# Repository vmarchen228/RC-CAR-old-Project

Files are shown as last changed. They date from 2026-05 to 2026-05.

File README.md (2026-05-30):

# RC Car Project

## Overview

This project involved designing and building a remote-controlled (RC) car as part of a college engineering project. The objective was to develop a functional vehicle capable of wireless control while integrating mechanical, electrical, and embedded systems concepts.

## Features

* Wireless remote control operation
* DC motor drive system
* Steering mechanism using servo motors
* Battery-powered system
* Custom chassis assembly
* Real-time control through a handheld transmitter

## Hardware Components

* Microcontroller (Arduino Uno/Nano)
* DC motors with motor driver module
* Servo motor for steering
* Wireless communication module (Bluetooth/RF)
* Rechargeable battery pack
* RC car chassis and wheels

## Software

The control software was developed in C/C++ using the Arduino IDE. The program handled:

* Motor speed control
* Steering angle adjustment
* Wireless command processing
* Safety and power management functions

## Results

The RC car successfully demonstrated wireless movement, steering control, and reliable operation during testing. The project provided practical experience in embedded systems, electronics integration, programming, and system debugging.

## Skills Developed

* Embedded Programming (C/C++)
* Arduino Development
* Electronics and Circuit Design
* Motor Control Systems
* Wireless Communication
* Mechanical Assembly
* Troubleshooting and Testing

## Future Improvements

* Autonomous navigation capabilities
* Obstacle detection using ultrasonic sensors
* Camera integration for FPV control
* Improved battery management system
* Mobile application control
RC CAR project

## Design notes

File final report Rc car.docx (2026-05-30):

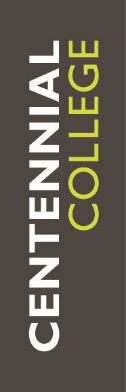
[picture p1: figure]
Image result for centennial college logo

School Of Engineering Technology and Applied Science (SETAS)

Advanced Manufacturing and Automation Technology (AMAT)

Automation and Robotics Technology

ROBO356- Design and Development Project 1

Section: 009 (Group 2)

Project Name: Remote Control Car

Title of Submission: Progress Report 1

Date: 17.10.2020

Professors: Alaeddin Bani Milhim

Florin Bratu

Submitted By:

Yaroslav Ishutko (301004764)

Vladislav Marchenko (301005635)

Declaration of Authorship (By Group 2)

We, Yaroslav Ishutko and Vladislav Marchenko, confirm that this breakdown of authorship represents our contribution to the work submitted for assessment and our contribution is our own work and is expressed in our own words. Any uses made within the Technology Report of the works of any other author, separate to the work group, in any form (ideas, equations, figures, texts, tables, programs), are properly acknowledged at the point of use. A list of the references used is included.

Abstract

Remote Control Car project is conducted by Group 2 on ROBO 356 section 009 to successfully design, build, troubleshoot and operate a remotely controlled vehicle capable of riding, steering, climbing low-pitched (up to 23°) ramp, gripping and transporting light objects (small coffee cup). As for week 5, all major aspects of vehicle design are finalized: it is 4-wheel, rear drive machine with a newly-developed “true” steering system controlled by servo motor. Major power components, such as battery, motors and a gripper are shifted to the back, while electronics and signal components (Ultrasonic sensor, Bluetooth module, Arduino UNO microcontroller platform) are located in front. It simplifies wiring, signal processing and allows to avoid extra high-to-low energy buffers (Arduino platform consumes 12V and is capable itself to share 5V for several field devices). Mechanical design description is supported by detailed in-scale 3D construction schematics of the vehicle and its particular components. Vehicle theoretical performance is analyzed, predicted and proved with all necessary formulas, it includes: Driving net force, Maximum vehicle speed, Steering Force, Gripping Force. Finished, ongoing and future construction activities are listed in chronological order and precisely described. As stated, major focus is held on assembling and testing steering mechanism – brand new and raw in design, but promising and unique feature. As a result of ongoing analytical and research process some minor changes were implemented in design besides steering. For example, it was decided to improve gripper design for higher safety and reliability. Finally, related and used references are accurately listed, as well, as descriptions to various formulas.

Table of Contents

- Cover Page 1
- Declaration of Authorship 2
- Abstract 3
- List of Illustrations 5
- Introduction 6
- Construction Activity
  1. Steering System 9
  2. Drive system construction 11
  3. Electrical/Power system construction 11
- Troubleshooting Activity 12
- Conclusion 15
- Bibliography (List of References) 16
- Glossary of terms 17
- Formula’s List 18

List of Illustrations

- Figure_1: Overall mechanical design of the vehicle 8
- Figure_2: Steering System Design 10
- Figure_3: Initial L-shape design 13
- Figure_4: Final L-shape design 13
- Figure_5: Gripper Schematic 14

Introduction

The goal of the project is to design a vehicle that will be capable of moving forward, backward, overcoming the inclined ramp , as well as to steer, grip the coffee cup and deliver it to the designated location. The car must be operated remotely and should be able to complete the task in 4 min. The cup must not touch the floor while being gripped.

The design has some limitations that should be considered while designing the vehicle.

List of limitations include such parameters:

1. Vehicle should be safe to competitors
2. Overall vehicle dimensions must not exceed 10 by 16 inches and be able to be carried by one person
3. Vehicle wheels must be in a range of 2 to 6 in in diameter
4. The only power supply that could be used is 12V Battery
5. To propel the vehicle only to specific 12V DC motors were given
6. No wood, toy components, glue , tape breadboard, are allowed
7. Vehicle must be self-contained

The design objective was to satisfy all the criteria mentioned above. To achieve the assigned configuration, the simplified physical- mathematical model was used to design the car for the scratch.

First of all it was decided that the vehicle will run on 4 wheels , 2 of which will be directly connected to the shafts of the 12 V DC motors. The other 2 wheel will be used in the steering mechanism. As a control will be used an app on the phone

Secondly, the design was based on the provided materials and parts. For example, the DC motors were meant to be attached to the base via L- bracket of specified shape. The base was supposed to be made of 10 by 16 inch aluminum plate and be able to old the battery an the rest of the components on it. Taking into consideration all the parameters it was decided to design from scratch the unique steering system with shafts, which will be connected to the wheels, and will be operated with help of servo motor to rotate left and right.

Thirdly, to satisfy the goal of the project additional components were obtained. These include: gripper operated by servo motor to grip the cup, Arduino UNO microcontroller as main logic element, Bluetooth module compatible with Arduino to connect to the phone app, Motor drive shield for Arduino to control 2 DC motors, Ultrasonic sensors to measure distance to objects, power switch and fuse for system safety and to avoid shortage in the wiring, LEDs and resistors for indication motion forward, backward or obstacle.

Design Section

Mechanical

The primary idea of mechanical design was to estimate the required base plate dimensions to fit the necessary components : L – brackets, DC motors, steering Mechanism, Battery, Arduino UNO, Bluetooth module, Motor shield, gripper and Ultrasonic sensor. By using the 3D Engineering software Inventor, all parts were drawn accurately to their real- life dimension and placed on the base plate. The estimated length was determined as 12 in. The length for Full steering system including Servo motor, and Steering mechanism was estimated in 5 inch length. By placing the 2 DC motors on the plate opposite to each other it was determined that the required width of the project will no exceed 7 inches.

The mechanical design had to satisfy 3 main features:

1. Motion Forward/Backward
2. Steering
3. Gripping the cup

For motion the Forward/Backward the 2 DC motors were used at the rear, in other words the vehicle was designed to have rear drive. DC motors were connected to the L brackets which itself were connected to the base plate at the rear . All connection were done by Hex cup bolts.

For Steering purpose the Steering Mechanism was designed because it has an advantage of more precise control.

While designing the steering mechanism few criteria were followed such as

1. The dimensions of the steering should not exceed 7 by 5 inch;
2. Shaft for the steering should be on the same level as shaft of the DC motor to avoid the base plate inclination.
3. Steering have to be attached to the base plate mechanically

By considering all of the above it was decided to design 2 Angle blocks of the L- Shape with shafts that will be connected to the base via bolts. From the beneath Angle blocks will be supported by the plate and from top by the base plate itself. To make sure that the Angle blocks steer to the same angle they were both attached to each other by the Steering Angle which will be connected to the servo later. By implying such construction the Angle blocks were lined up and were steering at the same angle when the Steering angle was rotated.

For Gripping the cup, the prototype of the Gripper was ordered and was modified.

The modification of gripper included facing off the unnecessary material from it claws and making the certain bolted connection to the servo motor and later to the plate itself.

After all main components were attached to the base plate, the central of mass was found and the rest of the components were placed to achieve equal weight load of rear drive and the steering mechanism. For such arrangement the heaviest component 12 V battery was placed between these two points.

All of the components were attached to the base plate by bolts except for the LEDs.

They were fitted in a specific bracket and then the bracket was tightly fitted to the base plate holes for the LEDs.

Two LEDs are present at the front and at the rear side for indication of Forward and Backward motion respectively.

The ultrasonic sensor was mounted at the front on holding bracket first and then attached to a 7 inch long holding panel that was attached to the base plate.

The Gripper which consists of Gripper and servo motor was decided to mount at the rear.

The battery was placed between Gripper and Arduino UNO, motor shield was placed at the top of the Arduino microcontroller as well as the Bluetooth module. Servo motor for the steering was placed between Arduino and ultrasonic sensor.

The secured mounting of battery and steering servo were achieved using holding plates tightened to the base plate by bolts foe each of them.

Switch and Fuse were placed closely to battery to avoid long wiring.

For more information regarding Mechanical Design please refer to the A

- Motor speed is 160 RPM (Zhengke Motor, 2020). The diameter of chosen wheels is 45 mm. These values will allow our car to achieve a maximum speed of 0,71m/s.

Vmax=RPMmax×L (2 ×π×R)

Lwheel = = 0.2673m

Vmax. = 160RPM*0.2673m (per rotation) = 42.77 m/minute ~ 0.71

- According to our calculations the approximate weight of the vehicle is around 2.5 kg. The torque produced by the motors is 39.24N*cm (Zhengke Motor, 2020) which will allow us to acquire a force of 34.8 N.

Freq. – force required to climb a ramp

Freq. = Ffr. + Fs. (Force of friction + Force of slip)

Freq=mgcos(a)×n+mgsin(a)

F req.= 2.5kg * 9.81m/s^2 * cos(23°) * 0.7 + 2.5kg * 9.81m/s^2 * sin(23°) = 25.39N

Fm - force provided by motors

Fm=2×T/R

Fm. = 2 * 39.24 N-cm /2.255cm = 34.80 N

This force is enough for the car to climb a ramp with an angle of 23 degree.

(Note* Actual Torque provided by DC motors, and, as a result, Motor Force is significantly higher than stated in manual)

- The steering servo motor will produce a Torque of 4 kg/cm (HITEC RCD USA, 2020). Considering the weight of the car is 2.5 kg and that most of the weight is concentrated on the Rear Drive. The weight we consider on steering wheels is 0,7kg. The mechanical coupling gives us approximately 4cm of lever.

F=T/L=4(kg)/(cm)/4 cm=1kg (Erjavec, 2002)

Therefore our car will have enough force to steer as F>W.

- To hold and transport a coffee cup securely F holding supposed to be greater than a cup weight.

Wcup (with ping-pong balls) ~ 25g * 9.81m/s^2 / 1000 ~ 0.25N

T=W×d , (distance from the motor shaft to the gripper contact point)

Thold = 0.25N * 7cm = 1.75 N-cm

Actual T of servo motor = 40.21 N-cm

sf=(Tac)/(Thold)

sf ~ 22 – Great safety factor ensures Cup is held securely even during acceleration and motion at maximum speed.

(Note* Presented calculations are also mentioned and justified in Milestone 2)

Construction Activity

The construction of the car consists of the three important parts.

1. The construction of the Steering System
2. The construction of the rear drive
3. Attachment of the components to the base plate
1. Steering System Construction

Our construction activities started with manufacturing parts for the steering mechanism and assembling the parts into one single Steering Assembly.

Our Steering Assembly primarily includes

1. 2 L-shape parts referred as Part A
2. 2 wheel shafts referred as Part A1
3. 2 Holding Plates referred as Part D
4. 1 Steering plate referred as Part B
5. 1 Motor-steering junction referred as Part C
6. 4 Socket Cap screws with washers and nuts

3 weeks are assigned for construction of the Steering mechanism. The activities are performed according to the schedule without delays.

As of date 10.11.2020 (Week4) we started construction of Steering Assembly

Part A manufacturing started and a rough L shape was obrained using Saw and Drill. (Week4, Vladislav Marchenko)

Future activities includes:

1. Milling the rough L-shape to acquire the precise dimensions needed (Week5, Vladislav Marchenko)
2. Drilling 3 holes in the Part A ( Week 5, Yaroslav Ishutko)
3. Manufacturing of Part A1 is required before obtaining the full shape of Part A ( Week 5, Yaroslav Ishutko)
4. The press fit of the shaft A1 into Part A (Week 5, Yaroslav Ishutko)
5. Manufacturing of parts D,C, B (Week5-6, , Yaroslav Ishutko)
6. Assembling of the Steering Mechanism ( Week6, Vladislav Marchenko)
2. Drive system construction

Second step of the construction involves attaching the rear drive to the base plate.

The whole construction activities consists of

1. Attaching the DC motors to the L brackets ( Week 7, Yaroslav Ishutko)
2. Drilling holes on the base plate to attach the L brackets and the Steering Assembly(Week 7, Vladislav Marchenko)
3. Attaching the L brackets, Steering Assembly to the plate, attaching wheels to the motor’s shafts and to the steering shafts. ( Week 7-8, Vladislav Marchenko)
3. Electrical/Power system construction

Third step is to attach the Arduino UNO, Bluetooth module, battery, ultrasonic sensor, gripper, motor drive shield, steering servo moto to the base plate.

Construction consists of:

1. Drilling holes on the base plate to attach the components with the fasteners. (Week 8, Yaroslav Ishutko)
2. Tighten the components to the plate with bolts and nuts ( Week8, Yaroslav Ishutko)

Troubleshooting Activities

Due to ongoing analysis of initial mechanical design and following troubleshooting in terms of optimization of car performance a number of changes were made. It included 1 major mechanical design change and 2 supplementary changes not reported in Milestone 2.

1. Development of “true” steering system

It was decided from the beginning to have rare drive car, meaning that both power wheels attached to 2 DC motor would be located on the back of the car, rather than in front. It satisfied our strategy to separate low-power (signal) and high-power (energy) systems. While Battery would be located closer to motors, powering them with 12V DC, major electrical components (Ultrasonic sensor, Bluetooth module ) would be located in front and powered with 5V by Arduino motherboard located in center-front part of the car. Thus, we solved 2 problems: firstly, we simplified wiring, secondly, we avoided using extra voltage step-down transition.

However, after comprehensive analysis it was decided to give up on steering by speed difference of power wheels. Rare drive and shifted back center of gravity made speed difference steering unreliable method. A completely new steering method had to be developed.

After gathering basic information about steering systems and car transmissions new unique steering system for Remote Control Car was developed. It came down to an idea of controlling wheels with servomotor. 2 L-shaped parts (Part A) are connected to wheels by pressing wheel shaft into one of its ends. L-shaped parts can rotate on shafts of a frame (Part D) connected to car bottom. Special steering plate moved by a servomotor control rotation of L-shaped parts and, accordingly, wheels.

(To find out more about its operation and structure refer “XXX”and Figure X)

New system provides increased controllability of rear drive and satisfies initial design limitations.

2. Minor change in a design of a steering system component

Initial design of L-shaped part of a newly-developed steering system included variety of different dimensions and sizes for different part components. It was done to ensure minimal weight and ideal balance in center shaft. After discussing initial design with faculty it was decided to develop more uniform and simplified part design contributing to reliability and simplicity of construction. Furthermore, initial idea of machining the wheel shaft within the solid part was rejected. Instead it was decided to drill a hole on the end of the part and press fit a separate wheel shaft into it (assembly). Aluminum was chosen as a construction material due to its low density (as for metals) and satisfactory rigidity.

Initial L-shape design vs revised design

Initial L-shape design, Figure_3

3. Minor Gripper Modification

Since new steering system required a lot of time and resources to be designed and constructed it was decided, in terms of time and resources management, to find most universal and reliable gripper solution. A standard Actobotic gripper, compatible with all standard servo motors, was chosen and order from one of suppliers. It also was assured that gripper is large enough to grab a small coffee cup – maximum width of gripper is 4.20” with total diameter of a cup no larger than 3-3.5”.

However, after analysis of Actobotic Gripper shape, it was determined to cut down and polish internal side of gripper so its shape would be ideally suitable for transportation of a specific coffee cup and its internal teeth (on the middle) are removed so cup would not be damaged in any case (safety). Rubber material of the gripper was defined as a tolerant for such deformations

Gripper Schematic, Figure_5

Internal Teeth

Note: original image was retrieved from: www.robotshop.com/ca/en/actobotics-perpendicular-standard-gripper-kit-b.html

c

Conclusion

- Vehicle performance expectations are clearly stated: moving forward, backwards, climbing inclined ramp, steering, gripping the coffee cup and delivering it to the designated location while controlled remotely via Bluetooth.
- Final mechanical design of the vehicle is fully described: 4 wheels, rare drive, “true” steering system controlled with servo motor, physical division of power and signal components.
- Multiple supporting 2D, 3D vehicle/components schematics are provided
- Vehicle performance expectations towards its Driving net force, Maximum vehicle speed, Steering Force, Gripping Force are described and proved by realistic calculations based on engineering formulas and data sheet information. Formulas also have an extra detailed description
- Construction activities for the past, present and future time periods are listed in chronological order and clearly described with division of responsibilities between group members.
- Major mechanical and supplementary Troubleshooting activities that have been conducted are listed, justified and described in-detail.
- All used References are mentioned and listed in alphabetical order

Bibliography

- Erjavec, J. (2002). Manual transmissions and transaxles (3rd ed.). Albany, N.Y: Delmar Thomson Learning.
- HITEC RCD USA. (2020). Hitec HS-422 Servo Motor Manual

Retrieved from: https://www.dfrobot.com/product-152.html

- Roboshop. Actobotics Perpendicular Standard Gripper Kit B

Retrieved from: https://www.robotshop.com/en/actobotics-perpendicular-standard-gripper-kit-b.html

- Zhengke Motor. (2020). ZGB37RG (A6587) Motor Manual

Retrieved from: https://www.zhengkemotor.com/product/zhengkemotor_product_Dc_Gear_Motor_37mm_ZGA37RG_ZGB37RG.html

Glossary of Terms

Bluetooth – technology of wireless data exchange between fixed and mobile devices.

Microcontroller – compact integrated electronic circuit capable of conducting complex logical and mathematical operations upon receiving input data. In other words – compact and simplified micro computer.

Motor Shield/Driver – a device or a module that is designed to easily and accurately control multiple motors and their parameters (speed, direction, torque and position). Can be controlled by microcontroller, PLC, PC.

Rear drive or Rear-wheel-drive – form of vehicle transmission at which only rare wheels are powered and driven by motor/s.

Shaft – round rotating machine element that transmits output power.

Formula’s list

Force exerted by servo motor for steering:

F=T/L

Force required for the car to climb the ramp:

Freq=mgcos(α)×μ+mgsin(α)

Force 2 DC motors can provide:

Fm=2×T/R

Maximum Speed of the vehicle:

Vmax=RPM×Lwh(2×π×R)

Torque required to be produced by servo motor to hold the cup:

T=W×d

Safety factor for the gripper:

sf=(Tac)/(Thold)

Group 2 – Progress Report 1 14

Running Head: Remote Control Car

Remote Control Car

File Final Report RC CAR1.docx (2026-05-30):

Image result for centennial college logo

School Of Engineering Technology and Applied Science (SETAS)

Advanced Manufacturing and Automation Technology (AMAT)

Automation and Robotics Technology

ROBO356- Design and Development Project 1

Section: 009 (Group 2)

Project Name: Remote Control Car

Title of Submission: Final Report

Date: 13.12.2020

Professors: Alaeddin Bani Milhim

Florin Bratu

Submitted By:

Yaroslav Ishutko (301004764)

Vladislav Marchenko (301005635)

Declaration of Authorship (By Group 2)

We, Yaroslav Ishutko and Vladislav Marchenko, confirm that this breakdown of authorship represents our contribution to the work submitted for assessment and our contribution is our own work and is expressed in our own words. Any uses made within the Technology Report of the works of any other author, separate to the work group, in any form (ideas, equations, figures, texts, tables, programs), are properly acknowledged at the point of use. A list of the references used is included.

Final Project Report Contribution Table
Section: | Person responsible:
Title Page | Yaroslav Ishutko
Declaration of Authorship | Yaroslav Ishutko
Abstract | Yaroslav Ishutko
Table of Contents | Yaroslav Ishutko
List of Illustrations | Yaroslav Ishutko, Vladislav Marchenko
Introduction | Vladislav Marchenko
Mechanical Design | Vladislav Marchenko
Electrical Design/Software | Yaroslav Ishutko
Troubleshooting activities | Yaroslav Ishutko
Data Analysis | Vladislav Marchenko
Conclusion | Vladislav Marchenko
Recommendations | Yaroslav Ishutko
Bibliography | Yaroslav Ishutko, Vladislav Marchenko
List of Acronyms | Vladislav Marchenko
Glossary of Terms | Vladislav Marchenko
Appendices | Yaroslav Ishutko, Vladislav Marchenko

Abstract

Remote Control Car project was conducted by Group 2 on ROBO 356 section 009 to successfully design, build, troubleshoot and operate a remotely controlled vehicle. Project was initially planned on 13 weeks (later shorten to 11 weeks). Due to personal effectiveness of all members of Group 002 and excellent group schedule it was possible to reach all main goals (and present the result to faculty) be the week 11. Thus, RC Car was successfully designed and constructed regarding and referring to initial technical requirements and, as a result, not only fully satisfies it, but also possesses several unique features that significantly increase its efficiency and are the subject to be discussed further in Final Report. Final Report on RC Car reflects all the technical requirements of the project (RC car should be capable of riding, steering, climbing the ramp, transporting light objects, etc..), rationale for the methods used, methodology (design principles, components and actuators used and their justification), bibliography (scientific references that had influence and shaped an initial idea of the project), design and troubleshooting activities during 11 weeks of project research and construction, resulting data analysis ( comparing of calculated theoretical and actual test data regarding RC Car performance) and overall project conclusions. Besides, some recommendations on further design project_1 course development are included as well as all the references, acronyms, terms are presented and listed in corresponding sections after the main part of the report. Finally, all technical data, formula references, final RC Car software code as well as both mechanical and electrical design figures are presented in acronyms.

Table of Contents

- Cover Page 1
- Declaration of Authorship 2
- Abstract 3
- List of Illustrations 5
  1. List of Figures 5
  2. List of Tables 5
- Introduction 6
- RC Car Design 7
  1. Mechanical Design 7
  2. Electrical Design/Software 9
  3. Troubleshooting Activities 11
    - Gripper installation 11
    - DC Motors selection and adjustment 12
    - Front wheels installation 13
- Data Analysis 14
- Conclusion 15
- Recommendations 16
- Bibliography 17
- List of Acronyms 18
- Glossary of Terms 19
- Appendices 20
  4. Appendices A 20
  5. Appendices B 24
  6. Appendices C 25
  7. Appendices D 27
  8. Appendices E 29
  9. Appendices F 31

List of Illustrations

List of Figures

1. Standard Hitec Servo Motor dimensions 11
2. Stainless Steel Pan Head Phillips Screw 12
3. Wheel Axial Locating using Spring Pins (schematics) 13

List of Tables

1. Project Contribution Table 2
2. I/O table 9
3. Data Table 14

Introduction

The goal of the project is to design a vehicle that will be capable of moving forward, backward, overcoming the inclined ramp , as well as to steer, grip the coffee cup and deliver it to the designated location. The car must be operated remotely and should be able to complete the task in 4 min. The cup must not touch the floor while being gripped.

The design has some limitations that should be considered while designing the vehicle.

List of limitations include such parameters:

1. Vehicle should be safe to competitors
2. Overall vehicle dimensions must not exceed 10 by 16 inches and be able to be carried by one person
3. Vehicle wheels must be in a range of 2 to 6 in in diameter
4. The only power supply that could be used is 12V Battery
5. To propel the vehicle only to specific 12V DC motors were given
6. No wood, toy components, glue , tape breadboard, are allowed
7. Vehicle must be self-contained

The design objective was to satisfy all the criteria mentioned above. To achieve the assigned configuration, the simplified physical- mathematical model was used to design the car for the scratch.

First of all it was decided that the vehicle will run on 4 wheels , 2 of which will be directly connected to the shafts of the 12 V DC motors. The other 2 wheel will be used in the steering mechanism. As a control will be used an app on the phone

Secondly, the design was based on the provided materials and parts. For example, the DC motors were meant to be attached to the base via L- bracket of specified shape. The base was supposed to be made of 10 by 16 inch aluminum plate and be able to old the battery an the rest of the components on it. Taking into consideration all the parameters it was decided to design from scratch the unique steering system with shafts, which will be connected to the wheels, and will be operated with help of servo motor to rotate left and right.

Thirdly, to satisfy the goal of the project additional components were obtained. These include: gripper operated by servo motor to grip the cup, Arduino UNO microcontroller as main logic element, Bluetooth module compatible with Arduino to connect to the phone app, Motor drive shield for Arduino to control 2 DC motors, Ultrasonic sensors to measure distance to objects, power switch and fuse for system safety and to avoid shortage in the wiring, LEDs and resistors for indication motion forward, backward or obstacle.

RC Car Design

Mechanical Design

The primary idea of mechanical design was to estimate the required base plate dimensions to fit the necessary components : L – brackets, DC motors, steering Mechanism, Battery, Arduino UNO, Bluetooth module, Motor shield, gripper and Ultrasonic sensor. By using the 3D Engineering software Inventor, all parts were drawn accurately to their real- life dimension and placed on the base plate. The estimated length was determined as 12 in. The length for Full steering system including Servo motor, and Steering mechanism was estimated in 5 inch length. By placing the 2 DC motors on the plate opposite to each other it was determined that the required width of the project will no exceed 7 inches.

The mechanical design had to satisfy 3 main features:

1. Motion Forward/Backward
2. Steering
3. Gripping the cup

For motion the Forward/Backward the 2 DC motors were used at the rear, in other words the vehicle was designed to have rear drive. DC motors were connected to the L brackets which itself were connected to the base plate at the rear . All connection were done by Hex cup bolts.

For Steering purpose the Steering Mechanism was designed because it has an advantage of more precise control.

While designing the steering mechanism few criteria were followed such as

1. The dimensions of the steering should not exceed 7 by 5 inch;
2. Shaft for the steering should be on the same level as shaft of the DC motor to avoid the base plate inclination.
3. Steering have to be attached to the base plate mechanically

By considering all of the above it was decided to design 2 Angle blocks of the L- Shape with shafts that will be connected to the base via bolts. From the beneath Angle blocks will be supported by the plate and from top by the base plate itself. To make sure that the Angle blocks steer to the same angle they were both attached to each other by the Steering Angle which will be connected to the servo later. By implying such construction the Angle blocks were lined up and were steering at the same angle when the Steering angle was rotated.

For Gripping the cup, the prototype of the Gripper was ordered and was modified.

The modification of gripper included facing off the unnecessary material from it claws and making the certain bolted connection to the servo motor and later to the plate itself.

After all main components were attached to the base plate, the central of mass was found and the rest of the components were placed to achieve equal weight load of rear drive and the steering mechanism. For such arrangement the heaviest component 12 V battery was placed between these two points.

All of the components were attached to the base plate by bolts except for the LEDs.

They were fitted in a specific bracket and then the bracket was tightly fitted to the base plate holes for the LEDs.

Two LEDs are present at the front and at the rear side for indication of Forward and Backward motion respectively.

The ultrasonic sensor was mounted at the front on holding bracket first and then attached to a 7 inch long holding panel that was attached to the base plate.

The Gripper which consists of Gripper and servo motor was decided to mount at the rear.

The battery was placed between Gripper and Arduino UNO, motor shield was placed at the top of the Arduino microcontroller as well as the Bluetooth module. Servo motor for the steering was placed between Arduino and ultrasonic sensor.

The secured mounting of battery and steering servo were achieved using holding plates tightened to the base plate by bolts foe each of them.

Switch and Fuse were placed closely to battery to avoid long wiring.

For more information regarding Mechanical Design please refer to the A

Electrical Design/Software

To begin with, it is necessary to point out that Electrical Design as well as Software are usually much more flexible in terms of troubleshooting. This is due the fact that all electrical or electronic components and programming space are heavily standardized and are available in already built-in universal packages/platforms for a moderate price. At our particular project of constructing Remotely Controlled Car we have also decided to use already developed and manufactured well-known universal electronic devices and available (easily accessible) user-friendly software to control mechanical actuators and signaling devices.

The key component or, in other words, the “brain” of our system became an Arduino Microcontroller integrated in universal Arduino Microcontroller Platform – Arduino Uno. This device is very flexible, customizable and has decent computing power that fully satisfies system requirements and an amount of data to be operated during normal performance. When choosing Arduino Uno platform it was ensured that there is enough Input/Output points for the number of operating device to be interfaced with Arduino. The list of used electronic devices is: Servo Motor1 (steering function), Servo Motor2 (gripping function), Ultrasonic Sensor (sensing distance and avoiding collisions), Bluetooth Module (serial communication between operator and RC Car), 2 x DC motors (prime movers) and 3 x signal LED’s (Forward, Reverse motion and Amber collision light). During the process of designing the electrical signal schematics for the system, 14 digital I/O pins of Arduino UNO were assigned to different devices as follows:

Input/Output Table

Arduino Platform-to-Pololu Motor Shield (interconnected pins)
Motor Direction Input A | Pin D2
Motor Direction Input B | Pin D4
Motor Enable Input | Pin D6 (Pwm)
Motor Speed Input | Pin D9 (Pwm)

Pololu Motor Shield-to-field devices (wire connections)
Forward LED Output | Pin D10
Reverse LED Output | Pin D11
Amber LED Output | Pin D12
Servo 1 Signal/Pulse Output | Pin D3
Servo 2 Signal/Pulse Output | Pin D5
Ultrasonic Sensor Trigger Output | Pin D7
Ultrasonic Sensor Echo Input | Pin D8
TX to Bluetooth RX Output | TX/Pin D1
RX from Bluetooth TX Input | RX/Pin D0

Power Connections of Pololu Motor Shield
Battery (main power supply) 12V | VIN wire terminal
Battery (main power supply) GND | GND wire terminal
2x DC Motor “+” | M1A wire terminal
2x DC Motor “-“ | M1B wire terminal

Power Connections of Arduino Platform
Battery (main power supply) | Power port (by multi-purpose power cable)

Note that Arduino UNO Microcontroller Platform was fully interfaced (100% compatible) with Pololu Motor Shield (Motor Driver), meaning that each pin of Arduino was interconnected with corresponding pin of Pololu platform and, as a result, pins were shared. Pololu Motor Shield was used as a special high-power interface for low-power Arduino controller (low currents, 5V outputs) and high-power 12V outer system.

Researching the “Pololu Simple Motor Controller User’s Guide” by Pololu, it was found out that pins D2 and D4 would control motor’s direction (terminals A1 and A2), pin D6 acts as a motor’s movement enabler and, finally, pin D9 (PWM~ pin) is a motor speed Input. It is important to mention that 2 DC motors were wired together (parallel) to a single motor terminal. It saved 4 extra pins on Arduino/Motor Shield and ensured that both motors receive exactly same commands during operation, as needed.

Both, steering Servo and gripping Servo (Hitec servo motors were used) required 5V and GND (was taken from 5V output on Pololu Motor Driver) and a controlling signal from one of 14 digital pins. It was important for correct operation that the pins for both servo motors are “PVM” Output pins (~ sign). It was needed for proper control by applying a series of high-frequency pulse signals. Thus, pins D3 and D5 were chosen.

According to the “The HC-05 Bluetooth Module with Arduino” article, Bluetooth module needed only 3.3 V power source that was also presented on Arduino Motherboard Platform. Practically, it was proved that 3.3V is enough for uninterrupted operation. Thus, Bluetooth module had a separate reliable power supply. Pins for serial communications (Rx and Tx) were set as D1 and D0 respectively. Servo Motors were easy to control using special Arduino code library represented in Appendices: C.

Ultrasonic Sensor (HC-SR04) required signal pins to be configured as digital Input and Output. Pins D8 and D7 were chosen respectively and, later, configured. Sensor uses Arduino Timer Module to measure the distance having the speed of ultrasonic waves as known value. It measures time between sending and receiving reflected signal and, using, timing and program calculations, user is able to determine exact position. Sensor was powered by stable 5V Output.

3 signal LED’s received pins at last order, as there were absolutely no special requirements for them. Pins D10, D11 and D12 were assigned to 2 Forward, 2 Reverse and 1 Amber light. 330 resistor was wired between Output pin and each LED to ensure proper voltage drop (1.8V) on LED (5V Output pins) for their correct operation. All leads were isolated, so no shortage could occur.

For common sense safety purposes, 2 A fuse and Main Power Switch were installed between Main Power Source (12V Battery) and the rest of the system.

To learn more about electrical system design for RC Car – refer to Appendices B.

Troubleshooting activities

Gripper installation

Considering the fact that RC Car had to climb a steep ramp (~23*) it was decided that the gripper has to be mounted at a certain elevation as for the level of the car base plate. After standard Actobotics Gripper (Kit B) was found and chosen for our project due to its compatibility with a series of standard servo motors, its was decided to secure gripper on the top of the servo motor, while using bolts, secure them both to the base plate. This method satisfied our initial requirements, was easy to implement and was anticipated by servo motor and gripper mechanical structure. The only problem seemed in the availability of thin (to fit special mounting holes on gripper’s sides), but very long (gripper height together with servo motor height resulted in around 1.65” length) and rigid bolts. As Centennial College Inventory couldn’t satisfy our need, we (Group #002) conducted our independent research and found bolts of satisfactory size (6-32 Thread, 2-1/2" Long bolt). Set of 2 bolts, 2 nuts and 2 washers was acquired and used for successful and safe installation of gripper.

Figure 1, Standard Hitec Servo Motor dimensions

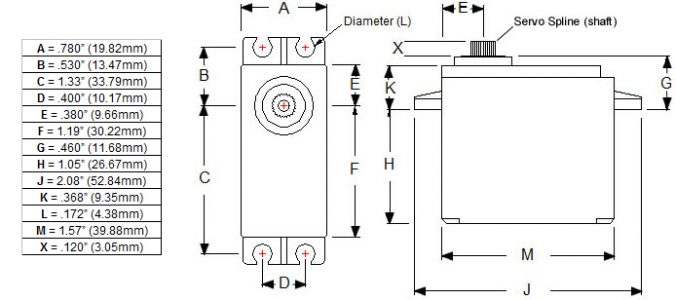
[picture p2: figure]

Note* Original image is reprinted from DFRobot , Hitec HS422 Servo.

Retrieved from: https://www.dfrobot.com/product-152.html

Figure 2, Stainless Steel Pan Head Phillips Screw

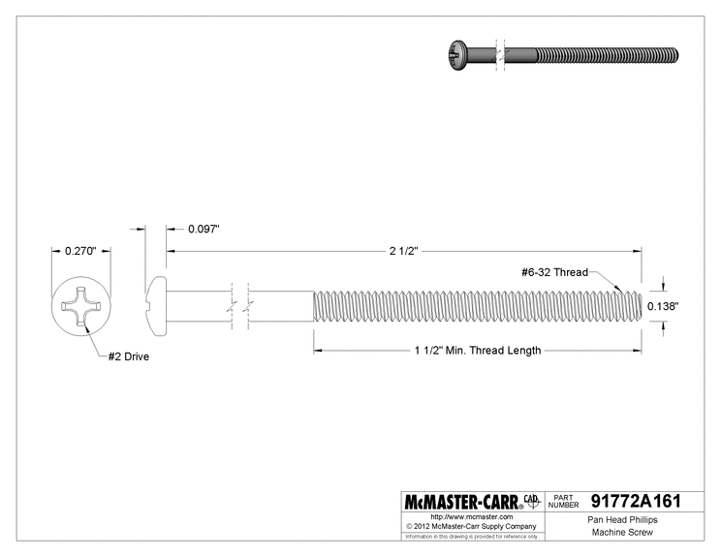
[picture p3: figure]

Note* Original image is reprinted from McMASTER-CARR, (2020), Passivated 18-8 Stainless Steel Pan Head Phillips Screw.

Retrieved from: https://www.mcmaster.com/91772A161/

DC Motors selection and adjustment

As per initial idea and construction design, steering was meant to be achieved by using separate front wheel transmission controlled by a servo motor. In this case, both 2 DC motors (prime movers) were connected to same output terminals, received same signals at the same time and had to rotate with exact same speed to achieve straight linear movement and precise control. 2 DC motors, acquired from Centennial College initially were proved to be asynchronous in terms of output speed, even though they both received voltage from the same source. To solve this problem, motors were exchanged on a pair with exact same characteristics (consumed current and voltage drop on motors was measured by multimeter: 108mA and 11.7V drop). Voltage drop, consumed current were repeatedly remeasured as motors were secured in L-shape brackets using multiple bolts. As a result – exact speed of both motors was achieved. Deviation of the car during normal performance was observed to be minimum (1-3* or 7-8 cm over 3 m distance).

Front wheels installation

Due to unique design of the car overall and of the steering structure in specific, there was a strict design requirement for both front wheels to spin or rotate freely on the shaft (press fitted into the rotating angle element of the steering system) while being reliably secured axially on the same shaft. To achieve this, it was decided to use tiny pins (pin – device commonly used to axially secure rotating elements on the shaft) from both sides of the each wheel – 4 pins in total. Holes were drilled on small and round shaft, so great precision was achieved using milling machine (up to 0.0001” precision). Wheels and corresponding pin holes for them were located on exact same distance from both sides to ensure precise steering. Holes’ diameter was only around 0.05”. Spring pin type was used – it expands while placed into the hole, thus preventing any slippage and unsecure fixation.

Figure 3, Wheel Axial Locating using Spring Pins (schematics)

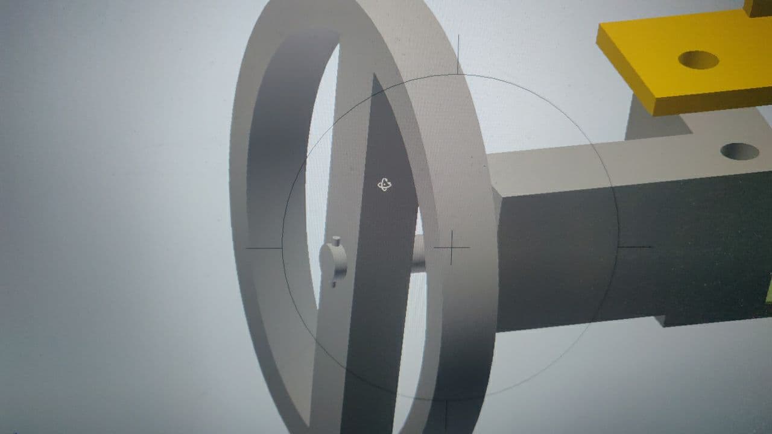
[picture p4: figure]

Note* Picture is taken from RC Car mechanical drawing/schematics - Appendices A

Data Analysis

Based on the acquired material and components it became possible to compute the maximum speed, torque, friction with surface and gripper holding force.

Motor Speed | 160 RPM
Wheels diameter | 45 mm
Wheels Circumference | 0,2673 m
Max Speed | 0,71m/s
Weight | 2,5 kg
Motors Toque (Total) | 39,24 N*cm
F required | 25,39 N
F acquired | 34,8 N
Steering motor Torque | 4 kg*cm
Steering Motor Force | 1 kg
Force to hold cup | 0,25 N
Torque achieved at the gripper | 40,21 N*cm
Safety factor for Gripper | 22

However in reality it was found out that the car achieve a slightly higher speed than was calculated , as well as the Actual torque produced by the motors appeared to be higher will allowed the car to climb even more inclined ramp than 23 degrees.

For the actual speed it was measured to achieve of 0,83 m/s while measuring time to reach 2,5 m for time of 3 s.

Construction of the steering mechanism was estimated to add additional 0,7 kg to total weight of the car and based on that number the servo motor required torque for steering was calculated .

The design was mostly symmetric, combined with synchronous rotating motors it allowed to achieve a straight motion on the test.

Due to firm connection to the base with the bolts, the vibration occurred during test was insignificant and therefore making the vehicle able to sustain self-contained for a long time.

The use of servo motor made it possible to achieve precise steering even during the maximum speed.

Conclusion

In conclusion, the designed vehicle managed to complete all the tasks and objectives that were set, furthermore the outcome of the project was more satisfactory than expected in terms of vehicle technical characteristics: the speed achieved was higher than anticipated , so was the ability of overcoming more inclined ramps and carrying more heavy objects. The straight motion became possible due to symmetric design and precise steering control. Overall, the method of applying physical-mathematical model, combined with designing the vehicle in the CAD engineering software was effective. The further design improvements are possible in achieving higher speed and acceleration by adding gear box to the rear drive and improving the steering system by adding additional motors to the front drive, thus making car full drive, or replacing motors with more powerful analogs.

Recommendations

Overall, Design and Development Project_1 course possesses satisfactory academic quality is intensive and has both theoretical and practical activities to be completed during the semester.

On the other hand, there certainly is a room for further development and improvements.

We introduced several possible improvements that, in our opinion, could contribute to the course in future:

- Theoretical background

From the practical experience of many students, 2 previous semesters of studying do not provide sufficient academic background and specific applicable knowledge that could help during comprehensive RC Car design and construction. We suggest to implement concepts of automation and automotive systems design, automotive motion and power transmissions and physics/calculations for power transmissions/drives as a part of some engineering courses prior to Design and Development Project_1. It also refers to the study of microcontrollers and C# programming – having both courses in same semester, students are not able to spend time effectively, as, most of the time, they do not possess enough knowledge to program car yet.

- Project Evaluation

We find it right to evaluate final outcome of student project. However, we suggest to evaluate design component rather than performance. First of all, the objective of the course is to learn, investigate and create. You should support unique decisions, “thinking out of the box” and creativity, rather than immediate effectiveness in particular situation. Especially, when every group has exact same power source and prime movers. In the end of the day it comes to: minor factors (that are even hard to account) and simple luck. Also, each project/design should be evaluated independently, as the last team in the strongest section may still be better than the best team in weakest section, yet, having totally different grades for the same performance.

- Inventory and Tools

Even though most of the machinery in College Machine Shop may be old, it still functions well. The only suggestion as for heavy equipment and machinery would be to acquire a number of equipment with higher precision for delicate/high-precision material processing. However, there is totally different situation with availability of various hand tools, minor details and raw material. It would be much better if student had access (while constructing a complex system) to a various materials (metal sheets, plastic, insulators, tubes) – not only occasional leftovers. Also, often used tools (end mills, chucks for milling, calipers, etc) are usually in poor condition and have to be replaced. Overall expansion of inventory volume and diversity would definitely contribute to the course quality and student performance.

Bibliography

DFRobot , Hitec HS422 Servo.

Retrieved from: https://www.dfrobot.com/product-152.html

Makersspaces.com, Arduino For Beginners.

Retrieved from: https://www.makerspaces.com/arduino-uno-tutorial-beginners/

McMASTER-CARR, (2020), Passivated 18-8 Stainless Steel Pan Head Phillips Screw.

Retrieved from: https://www.mcmaster.com/91772A161/

Pololu, (2020), Pololu Simple Motor Controller User’s Guide.

Retrieved from: https://www.pololu.com/docs/0J44

Sanjay Rajure (2019, May18), The HC-05 Bluetooth Module with Arduino.

Retrieved from: https://www.comprolive.com/2019/05/the-hc-05-bluetooth-transmitterreceiver.html

List of Acronyms

CAD – Computer Aided Drafting

RC – Remotely Controlled

DC – Direct Current

LED – Light Emitting Diode

GND – Ground

I/O – Input/ Output

Glossary of Terms

Bluetooth – technology of wireless data exchange between fixed and mobile devices.

Microcontroller – compact integrated electronic circuit capable of conducting complex logical and mathematical operations upon receiving input data. In other words – compact and simplified micro computer.

Motor Shield/Driver – a device or a module that is designed to easily and accurately control multiple motors and their parameters (speed, direction, torque and position). Can be controlled by microcontroller, PLC, PC.

Rear drive or Rear-wheel-drive – form of vehicle transmission at which only rare wheels are powered and driven by motor/s.

Shaft – round rotating machine element that transmits output power.

Appendices

A: (Mechanical Drawings)

B: (Electrical drawings/schematics)

Note* Electrical schematics left unchanged from Milestone 4

C: (Arduino Microcontroller program code)

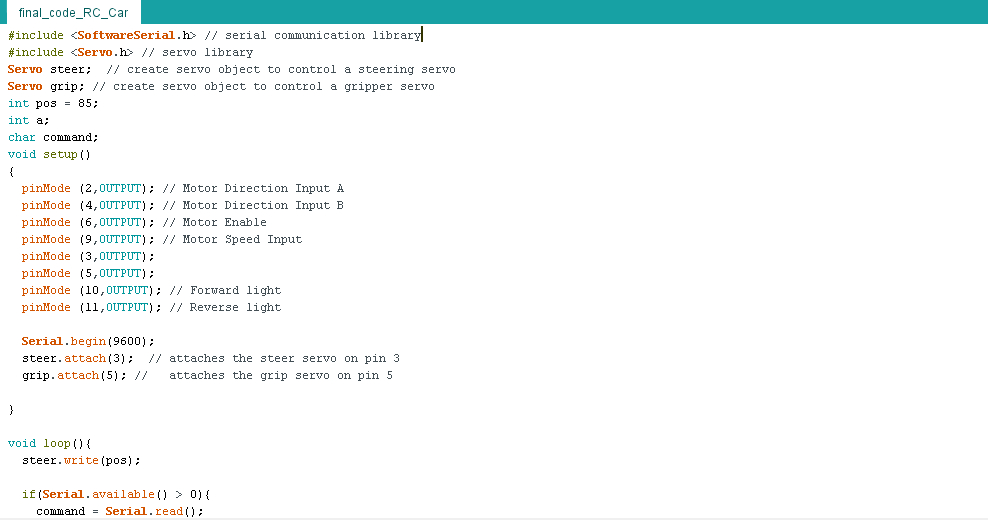
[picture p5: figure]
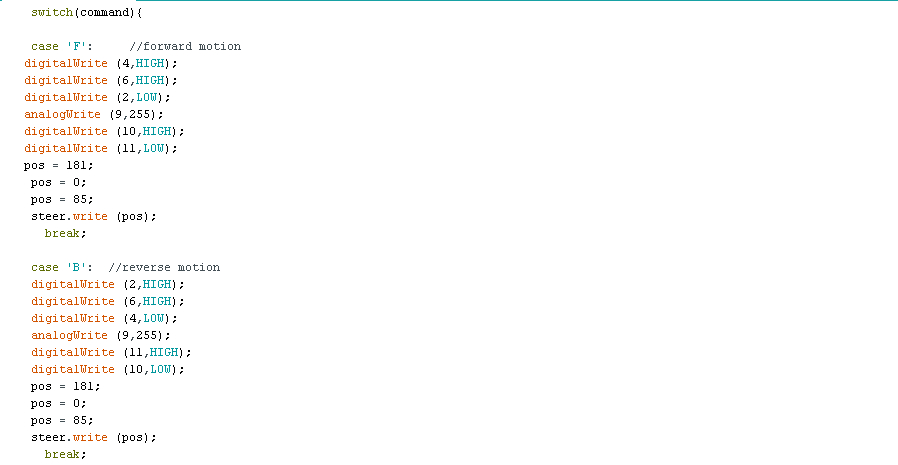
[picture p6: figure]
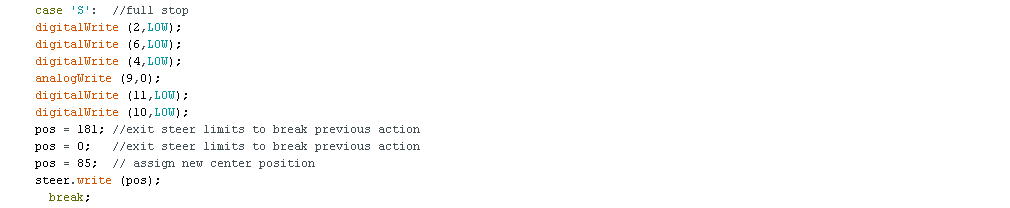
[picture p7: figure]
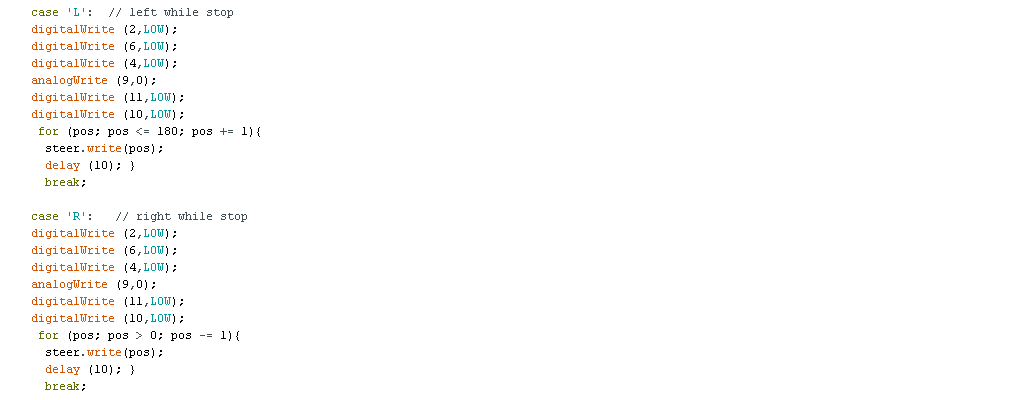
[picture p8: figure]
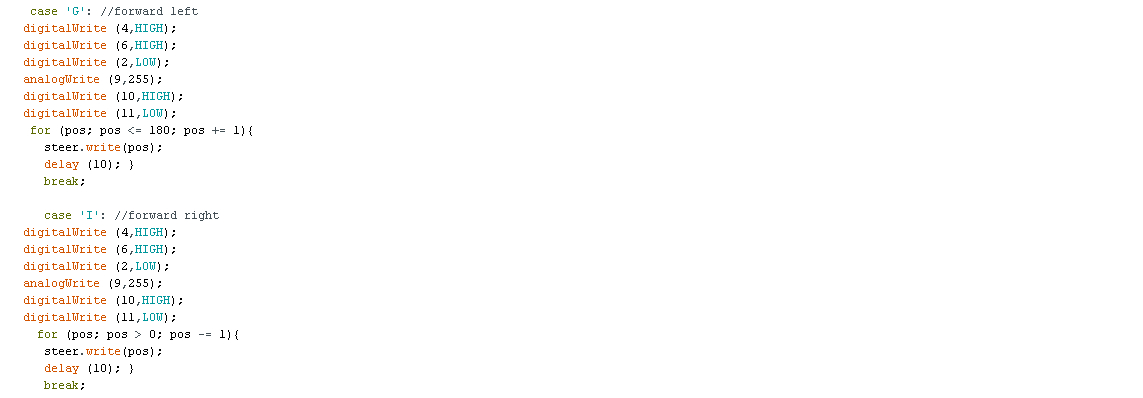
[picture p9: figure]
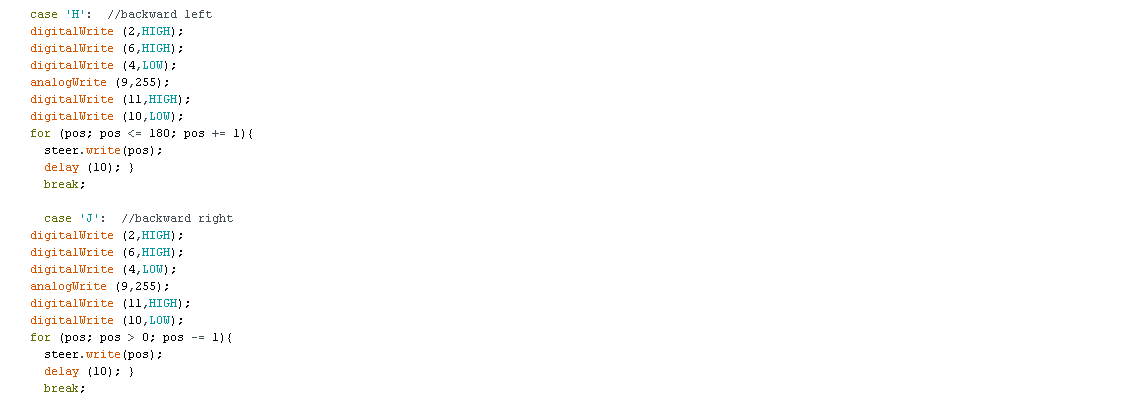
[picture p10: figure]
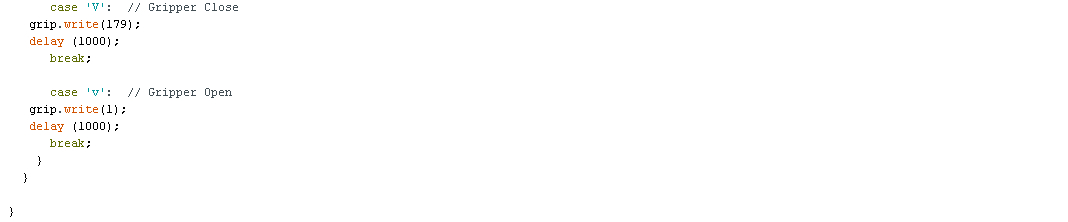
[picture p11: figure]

D: (Project Design Calculations – Formulas’ list and full calculation)

Force exerted by servo motor for steering:

F=T/L

Force required for the car to climb the ramp:

Freq=mgcos(α)×μ+mgsin(α)

Force 2 DC motors can provide:

Fm=2×T/R

Maximum Speed of the vehicle:

Vmax=RPM×Lwh(2×π×R)

Torque required to be produced by servo motor to hold the cup:

T=W×d

Safety factor for the gripper:

sf=(Tac)/(Thold)

Motor speed is 160 RPM. The diameter of chosen wheels is

45 mm. These values will allow our car to achieve a maximum speed of 0,71m/s.

Vmax=RPMmax×L (2 ×π×R)

Lwheel = = 0.2673m

Vmax. = 160RPM*0.2673m (per rotation) = 42.77 m/minute ~ 0.71

According to our calculations the approximate weight of the vehicle is around 2.5 kg. The torque produced by the motors is 39.24N*cm (Zhengke Motor, 2020) which will allow us to acquire a force of 34.8 N.

Freq. – force required to climb a ramp

Freq. = Ffr. + Fs. (Force of friction + Force of slip)

Freq=mgcos(a)×n+mgsin(a)

F req.= 2.5kg * 9.81m/s^2 * cos(23°) * 0.7 + 2.5kg * 9.81m/s^2 * sin(23°) = 25.39N

Fm - force provided by motors

Fm=2×T/R

Fm. = 2 * 39.24 N-cm /2.255cm = 34.80 N

This force is enough for the car to climb a ramp with an angle of 23 degree.

(Note* Actual Torque provided by DC motors, and, as a result, Motor Force is significantly higher than stated in manual)

The steering servo motor will produce a Torque of 4 kg/cm. Considering the weight of the car is 2.5 kg and that most of the weight is concentrated on the Rear Drive. The weight we consider on steering wheels is 0,7kg. The mechanical coupling gives us approximately 4cm of lever.

F=T/L=4 kg*cm/4 cm=1kg (Erjavec, 2002)

Therefore our car will have enough force to steer as F>W.

To hold and transport a coffee cup securely F holding supposed to be greater than a cup weight.

Wcup (with ping-pong balls) ~ 25g * 9.81m/s^2 / 1000 ~ 0.25N

T=W×d , (distance from the motor shaft to the gripper contact point)

Thold = 0.25N * 7cm = 1.75 N-cm

Actual T of servo motor = 40.21 N-cm

sf=(Tac)/(Thold)

sf ~ 22 – Great safety factor ensures Cup is held securely even during acceleration and motion at maximum speed.

E: (Project Expenses Table)

Bill of Materials
Component Name | Specifications | Quantity | Part # or Supplier Code | Manufacturer

Power components
Battery | 12 VDC, 1.3ah | 1 | AJC-D1.3S | AJC® Battery
DC Power Motor | 12 VDC, 160RPM | 2 | ZGB37RG(A6587) | Zhengke Motor
Wheels | 4.255 cm Radius | 4 | - | -
Servo Motor | 4.1 kg-cm Torque | 2 | HS-422 | HITEC RCD USA
Gripper | 4.20” /10.67cm Wide | 1 | 637096 | Actobotics
Power Switch | SPST | 1 | SWROC-011014 | -
Fuse+holder | 20mm, 2A | 2+1 | MDL-2 | Bussman

Signal Processing
Integrated microcontroller board | ATmega328P Microcontroller | 1 | A000066 | Arduino
Motor Driver (Shield) | Arduino-compatible | 1 | ARDMD-002507 | Pololu
Ultrasonic Sensor | 40kHz Frequency, 5V | 1 | HC-SR04 | Adafruit Industries LLC
Bluetooth Module | 20-30m Range, 2.4 kHz Frequency, 5V | 1 | HC-05 | Lafvin (Made in China)
LED | 20-25 mA, current rate, 1.8V drop | 5 | SLR-56VR3F | Rohm Semiconductor
Resistor | 330 Ohm, ¼ Watt | 5 | RB-Spa-1509 | Sparkfun Electronics

Cost of the project "RC Car"
Part # | Part Name | Price per unit in CAD | Quantity | Total in CAD
1 | Battery 12 V AJC-D1.3S | N/A | 1 | N/A
2 | DC motor geared 12V ZGB37RG | N/A | 2 | N/A
3 | Motor Driver ARDMD-002507 | 60 | 1 | 60
4 | Microcontroller Arduino Uno | 28 | 1 | 28
5 | Blutooth Module HC-05 | 5 | 1 | 5
6 | Servo motor HS-422 | 18 | 2 | 36
7 | Ultrasonic sensor HC-SR04 | 5 | 1 | 5
8 | LEDs, wires, resistors,etc | 20 | 1 | 20
9 | Wheels | N/A | 4 | N/A
10 | Actobotics Gripper | 16 | 1 | 16
11 | Switch, fuze | 12 | 1 | 12
| HST (13%) | | | 23,66
| | Total cost in CAD : | 205,66

F: (Original and Actual Timeline – Gannt Chart)

Original Timeline

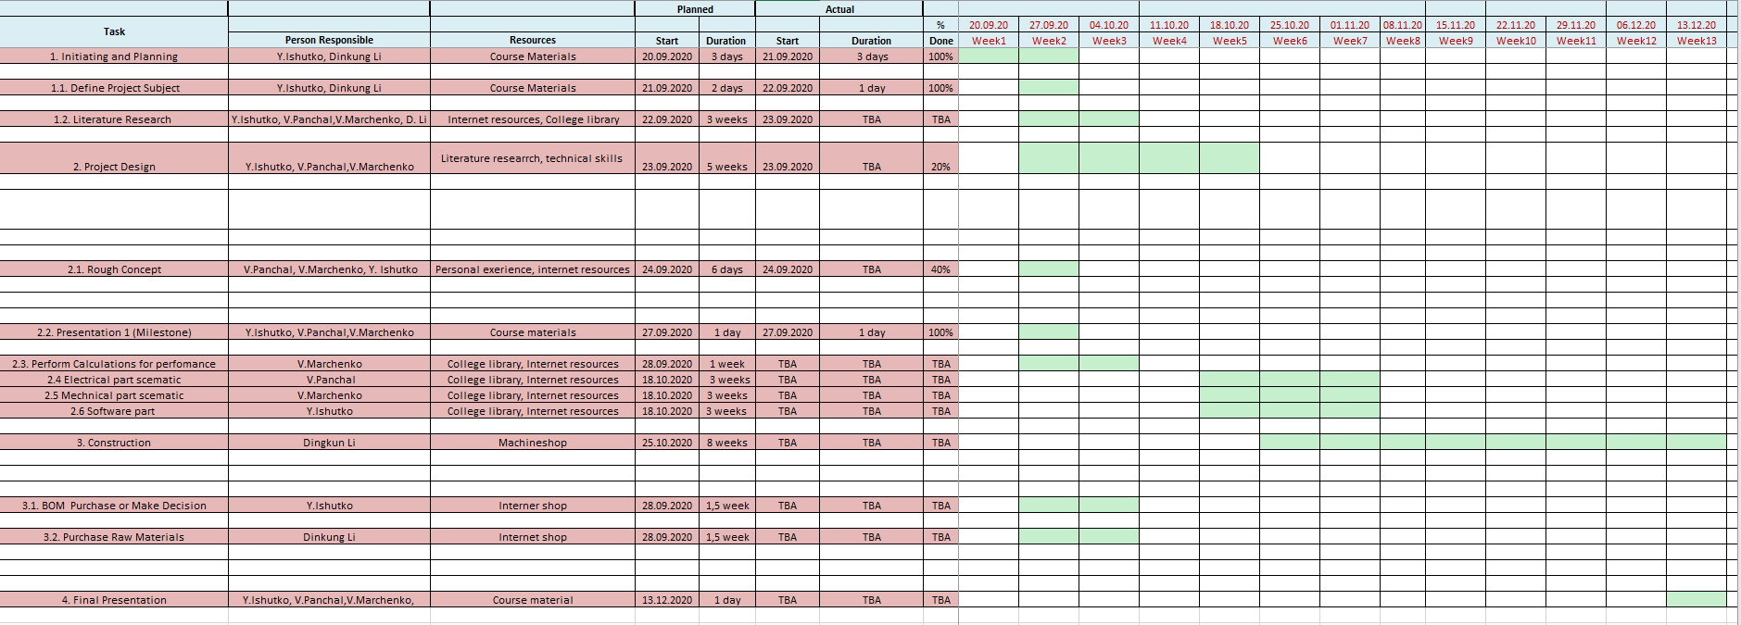
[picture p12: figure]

Actual Timeline

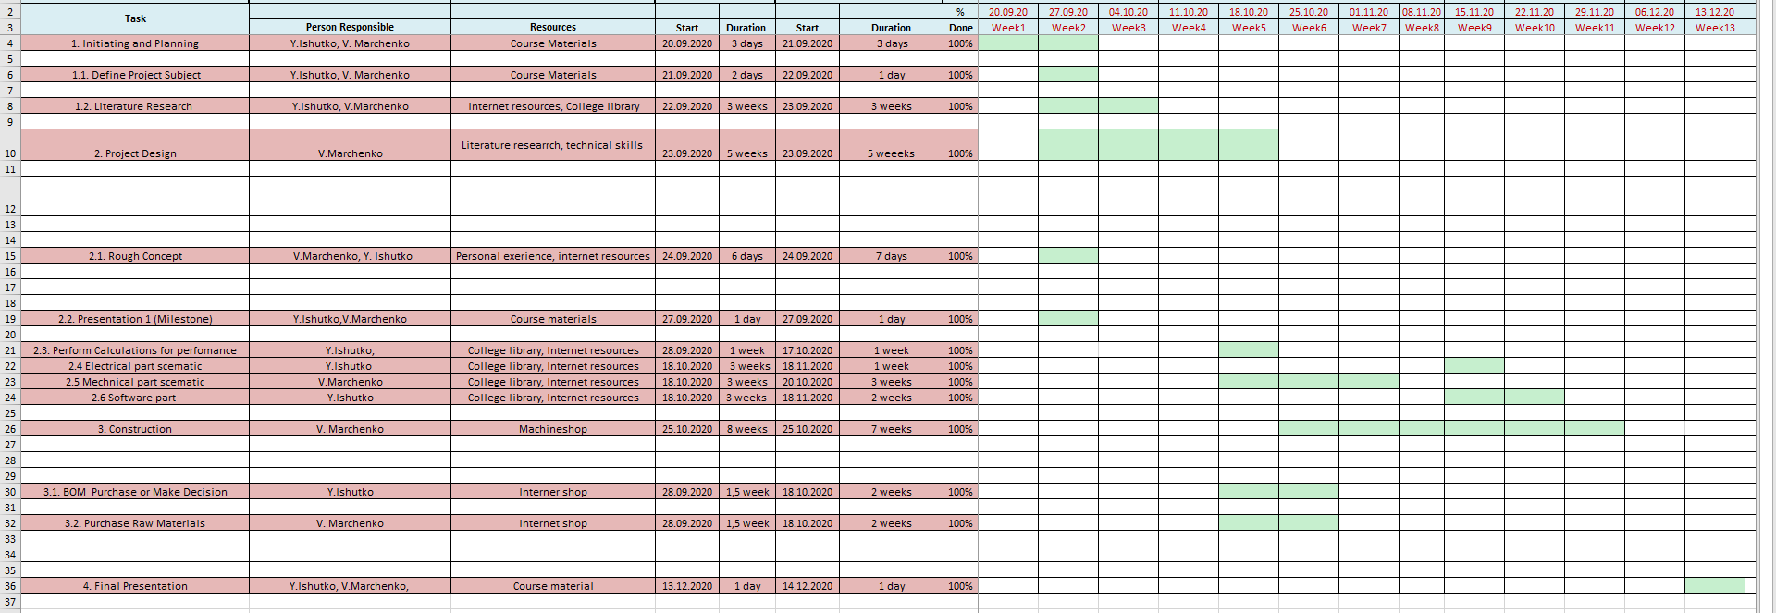
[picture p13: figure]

Group 2 – Final Report 31

Running Head: Remote Control Car

Remote Control Car

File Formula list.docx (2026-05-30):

List of formulas

F=T/L

Force exerted by servo motor for steering

Freq=mgcos(α)×μ+mgsin(α)

Force required for the car to climb the ramp

Fm=2×T/R

Force 2 DC motors can provide

Vmax=RPM×Lwh(2×π×R)

Maximum Speed of the car

T=W×d

Torque required to be produced by servo motor to hold the cup

sf=(Tac)/(Thold)

Safety factor for the gripper

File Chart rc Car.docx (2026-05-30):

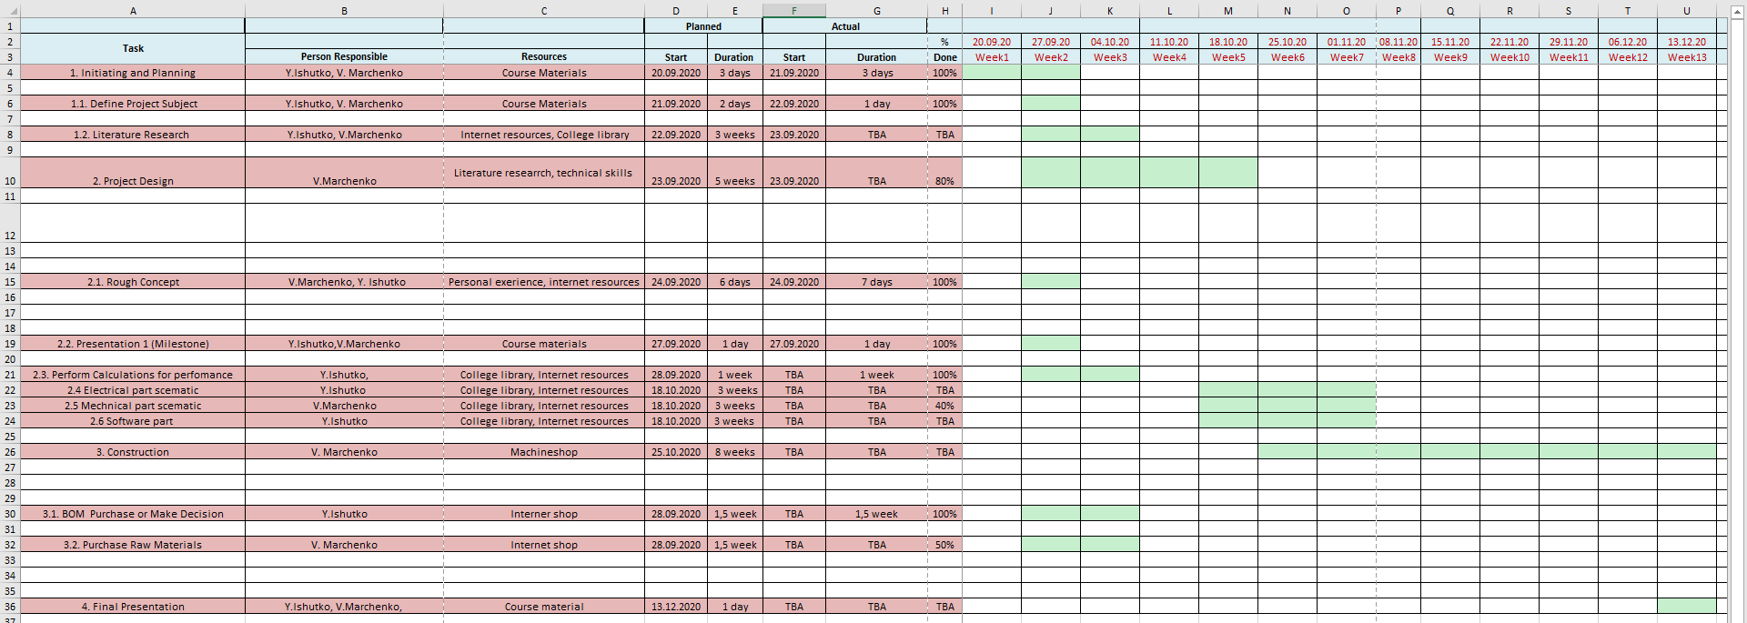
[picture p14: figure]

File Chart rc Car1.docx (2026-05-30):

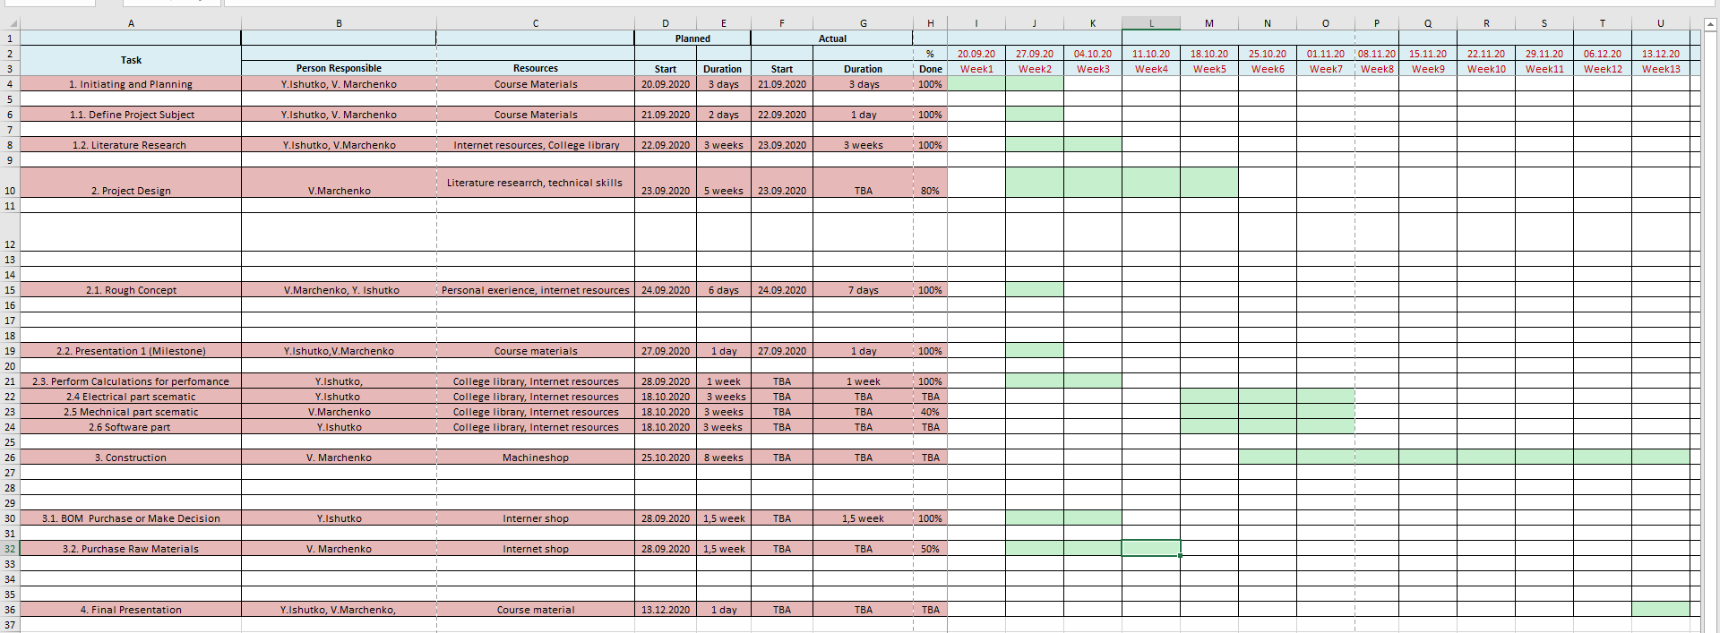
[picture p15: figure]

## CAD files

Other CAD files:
Components 1.dwg
Components 2.dwg
Components 3.dwg

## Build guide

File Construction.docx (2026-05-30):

Introduction

The scope of the project is to design a car that will be controlled via Bluetooth technology , and will be capable of moving forward, backwards, climbing the ramp inclined to a specific angle, steering, grip the coffee cup and deliver it to the designated location.

The design objective was to satisfy all the criteria mentioned above. By apply applying the simplified physical- mathematical model the type of motors and wheels size were determined .

It was decided that the car project would have 4 wheels, 2 DC motors, ultrasonic sensor, Bluetooth module, 2 servo motors, gripper, Arduino UNO microcontroller, 12V Battery, motor drive shield, power switch, fuse, LEDs and resistors.

The driving force will come from 2 DC motors and the car will have the rear drive. Ultrasonic sensor will be placed in the front to sense the obstacles, gripper will be placed on the back to pick up the cup . The battery will be placed between the gripper an the Arduino microcontroller. The rest of the components will be placed on the middle of the car plate. DC motors will be attached to the plate using the L-shape bracket. The steering system was designed to turn the wheels with the help of a servo motor, which will be placed on the plate. When the servo rotates, the shaft attached to it will move the steering plate, which will turn the wheels right or left depending on the motor direction of rotation.

According to our calculations the approximate weight of the vehicle is around 2.5 kg. Motor speed is 160 RPM( Zhengke Motor,2020). The wheels diameter is 85 mm. These values will allow our car to achieve a speed of 0,71m/s.

The torque produced by the motors is 16,67 N*cm (Zhengke Motor,2020) which will allow us to acquire a force of 70.93 N.

This force is enough for the car to climb a ramp with an angle of 23 degree.

The steering servo motor will produce a Torque of 4 kg/cm (HITEC RCD USA ,2020). Considering the weight of the car is 2.5 kg and that most of the weight is concentrated on the Rear Drive. The weight we consider is 0,9kg for the steering mechanism. The mechanical coupling gives us approximately 4cm of lever. F=T/L=4(kg)/(cm)/4 cm=1kg (Erjavec, 2002) Therefore our car will have enough force to steer as F>W.

Freq=mgcos(α)×μ+mgsin(α)

Freq. = Ffr. + Fs. (Force of friction + Force of slip)

F req. = = 2.5kg * 9.81m/s^2 * cos(22°) * 0.7 + 2.5kg * 9.81m/s^2 * sin(22°) = 25.1N

Force provided by motors: Fm.

Fm >= Freq. (25.1N)

Fm=2×T/R

Then: R=2×T/(Fm)

R = 2 * 39.24 N-cm / 25.1 N = 3.13 cm (maximum allowable wheel radius)

Note:

Our real wheels have a radius of 4.255cm . Performed calculations indicate that the car will no have enough power to climb the ramp. However, it was considered that real motor T is much higher than stated in present data sheet(Zhengke Motor,2020) . The motor model is different , threfore different power reading). Thus, 4.255 cm wheels are chosen and used in further calculations.

Maximum Vehicle Speed

Vmax=RPM×Lwh(2×π×R)

Lwheel = 2 * pi * 4.255 cm = 26.73 cm/r= 0.2673m/r

Vmax. = 160RPM * 0.2673m/r (per rotation) = 42.77 m/minute ~ 0.71m/s

To hold a cup F holding supposed to be greater than a cup weight.

Wcup (with ping-pong balls) ~ 25g * 9.81m/s^2 / 1000 ~ 0.25N

T=W×d , (distance from the motor shaft to the gripper contact point)

Thold = 0.25N * 7cm = 1.75 N-cm

Actual T of servo motor = 40.21 N-cm

sf=(Tac)/(Thold)

sf ~ 22 – Great safety factor ensures Cup is held securely even during acceleration and motion at maximum speed.

Construction Activity

The construction of the car consists of the three important parts.

1. The construction of the Steering System
2. The construction of the rear drive
3. Attachment of the components to the base plate
1. Steering System Construction

Our construction activities started with manufacturing parts for the steering mechanism and assembling the parts into one single Steering Assembly.

Our Steering Assembly primarily includes

1. 2 L-shape parts referred as Part A
2. 2 wheel shafts referred as Part A1
3. 2 Holding Plates referred as Part D
4. 1 Steering plate referred as Part B
5. 1 Motor-steering junction referred as Part C
6. 4 Socket Cap screws with washers and nuts

3 weeks are assigned for construction of the Steering mechanism. The activities are performed according to the schedule without delays.

As of date 10.11.2020 (Week4) we started construction of Steering Assembly

Part A manufacturing started and a rough L shape was obrained using Saw and Drill. (Week4, Vladislav Marchenko)

Future activities includes:

1. Milling the rough L-shape to acquire the precise dimensions needed (Week5, Vladislav Marchenko)
2. Drilling 3 holes in the Part A ( Week 5, Yaroslav Ishutko)
3. Manufacturing of Part A1 is required before obtaining the full shape of Part A ( Week 5, Yaroslav Ishutko)
4. The press fit of the shaft A1 into Part A (Week 5, Yaroslav Ishutko)
5. Manufacturing of parts D,C, B (Week5-6, , Yaroslav Ishutko)
6. Assembling of the Steering Mechanism ( Week6, Vladislav Marchenko)
2. Drive system construction

Second step of the construction involves attaching the rear drive to the base plate.

The whole construction activities consists of

1. Attaching the DC motors to the L brackets ( Week 7, Yaroslav Ishutko)
2. Drilling holes on the base plate to attach the L brackets and the Steering Assembly(Week 7, Vladislav Marchenko)
3. Attaching the L brackets, Steering Assembly to the plate, attaching wheels to the motor’s shafts and to the steering shafts. ( Week 7-8, Vladislav Marchenko)
3. Electrical/Power system construction

Third step is to attach the Arduino UNO, Bluetooth module, battery, ultrasonic sensor, gripper, motor drive shield, steering servo moto to the base plate.

Construction consists of:

1. Drilling holes on the base plate to attach the components with the fasteners. (Week 8, Yaroslav Ishutko)
2. Tighten the components to the plate with bolts and nuts ( Week8, Yaroslav Ishutko)

References

- Zhengke Motor (2020) ZGB37RG (A6587) Motor Manual

Retrived from : https://e.centennialcollege.ca/d2l/le/content/555717/viewContent/6551457/View

10/17/2020

- HITEC RCD USA (2020) Hitec HS-422 Servo Motor Manual Retrieved from : https://www.dfrobot.com/product-152.html
- Erjavec, J. (2002). Manual transmissions and transaxles (3rd ed.). Albany, N.Y: Delmar Thomson Learning.

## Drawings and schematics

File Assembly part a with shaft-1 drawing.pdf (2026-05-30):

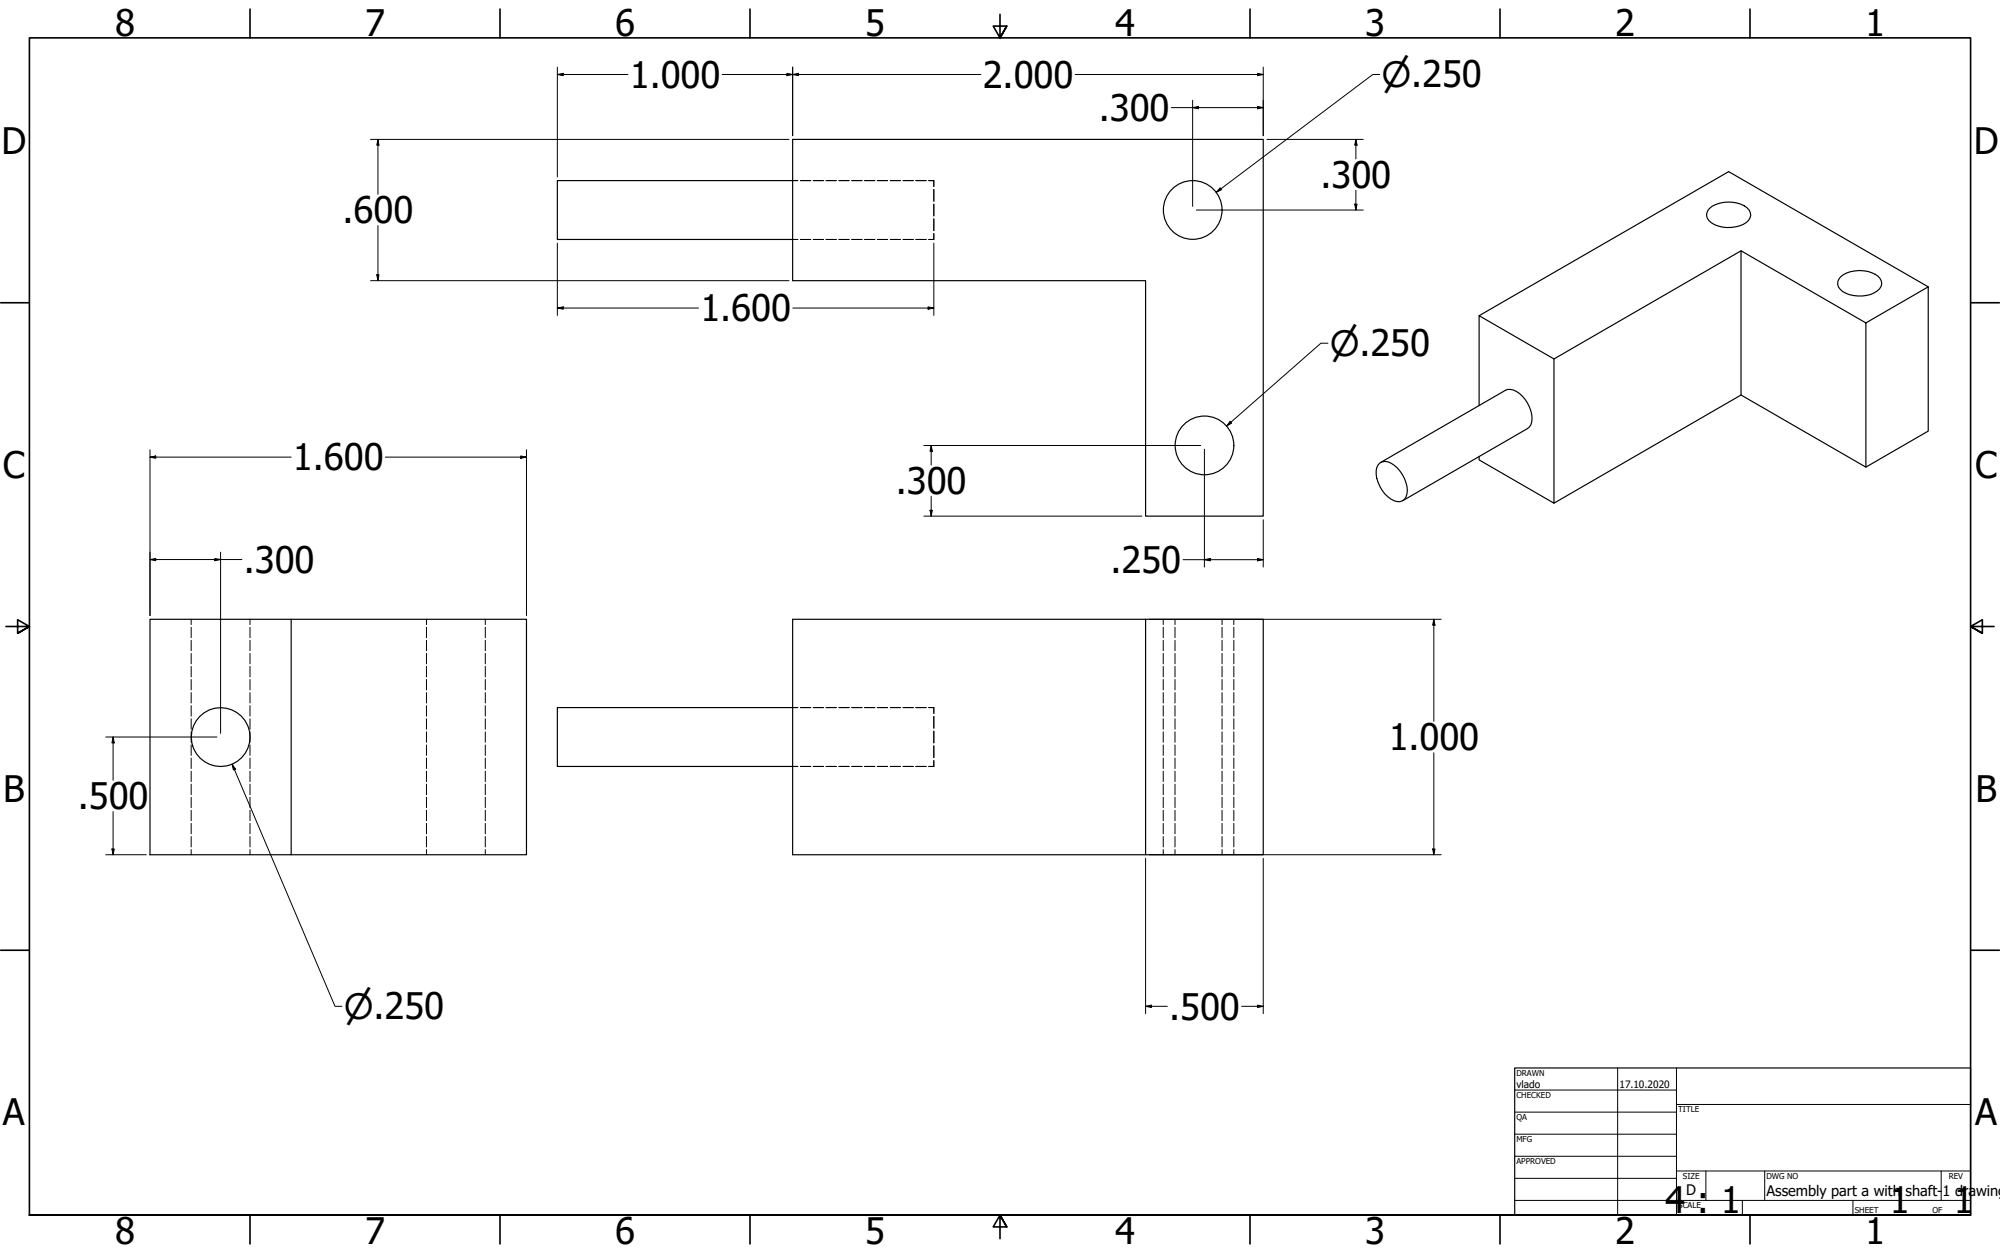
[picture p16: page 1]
SHEET

DRAWN vlado | 17.10.2020

CHECKED

MFG

APPROVED

SIZE D | DWG NO | REV

Assembly part a with shaft-1 drawing

SCALE

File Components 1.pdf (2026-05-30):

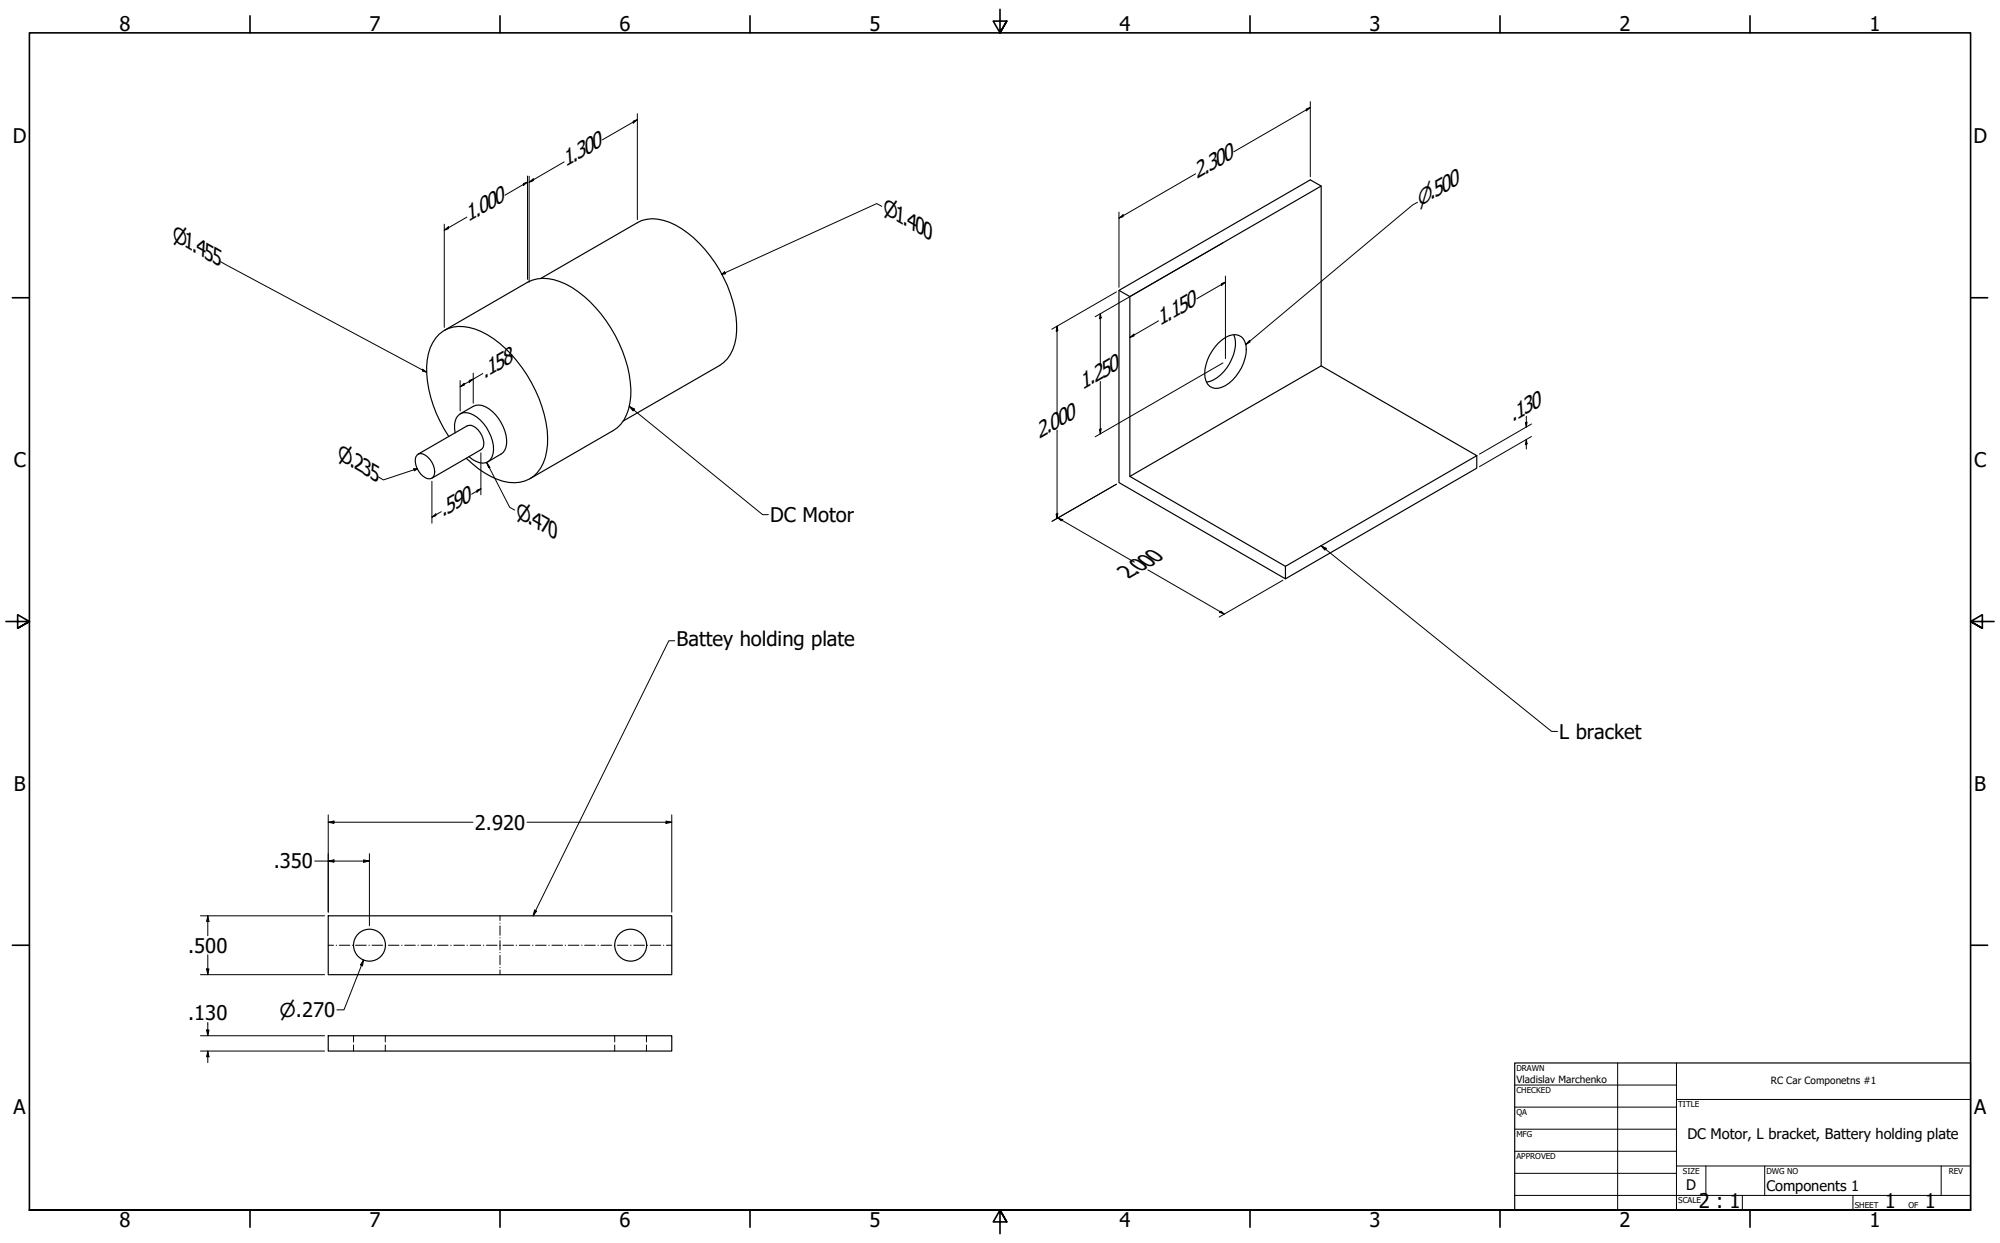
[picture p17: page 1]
DC Motor; L bracket

Battey holding plate

DRAWN Vladislav Marchenko | RC Car Componetns #1

CHECKED

TITLE
DC Motor, L bracket, Battery holding plate

MFG

APPROVED

SIZE D | DWG NO Components 1 | REV

2 : 1 SCALE | | SHEET 1 OF 1

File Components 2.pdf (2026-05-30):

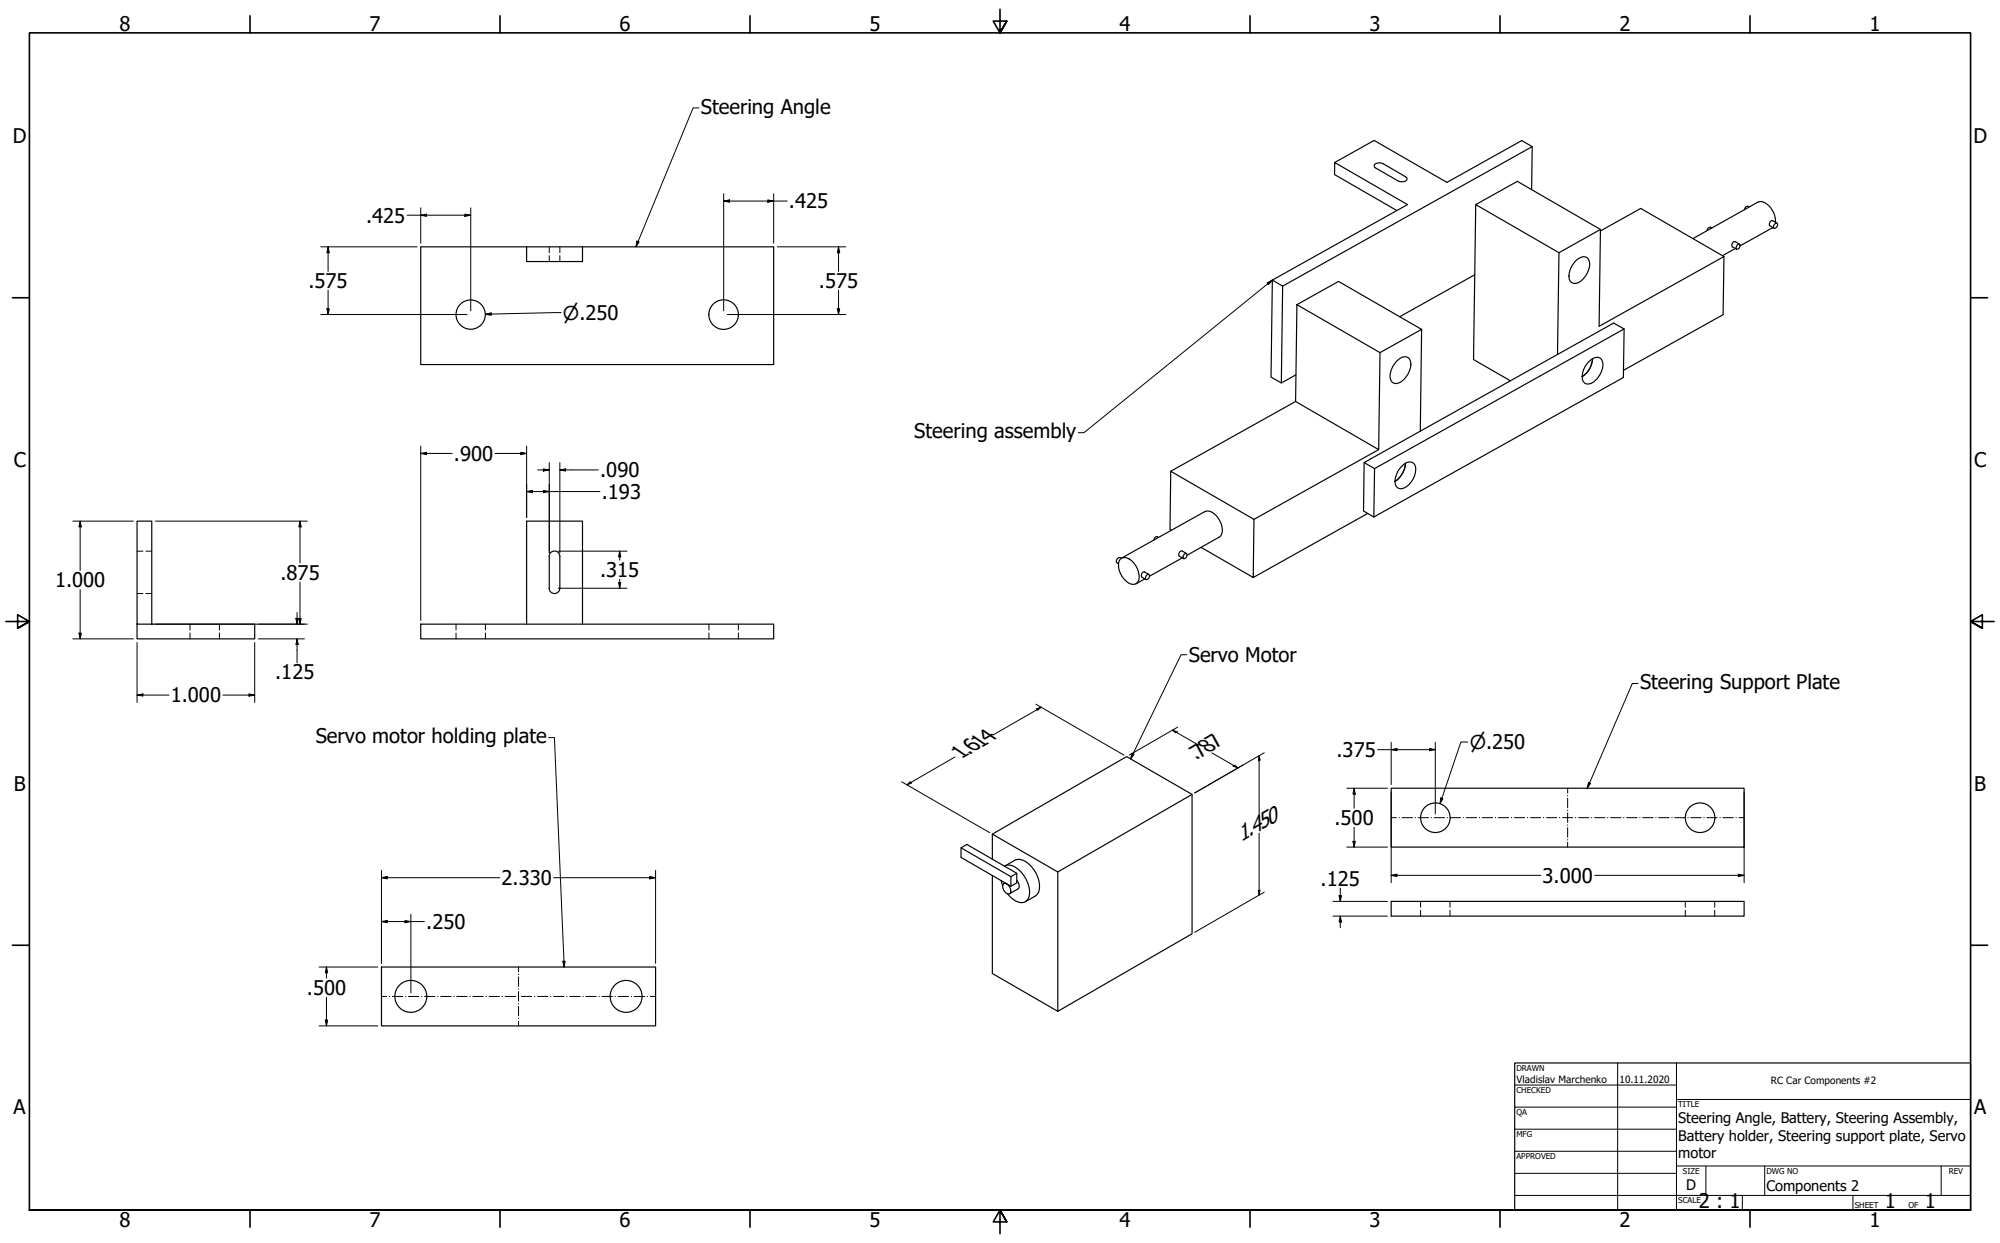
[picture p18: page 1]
Steering Angle; Servo Motor; Steering assembly

Steering Support Plate

Servo motor holding plate

DRAWN Vladislav Marchenko | 10.11.2020 | RC Car Components #2

CHECKED

TITLE
Steering Angle, Battery, Steering Assembly,
Battery holder, Steering support plate, Servo
motor

MFG

APPROVED

SIZE D | DWG NO Components 2 | REV

2 : 1 SCALE | | SHEET 1 OF 1

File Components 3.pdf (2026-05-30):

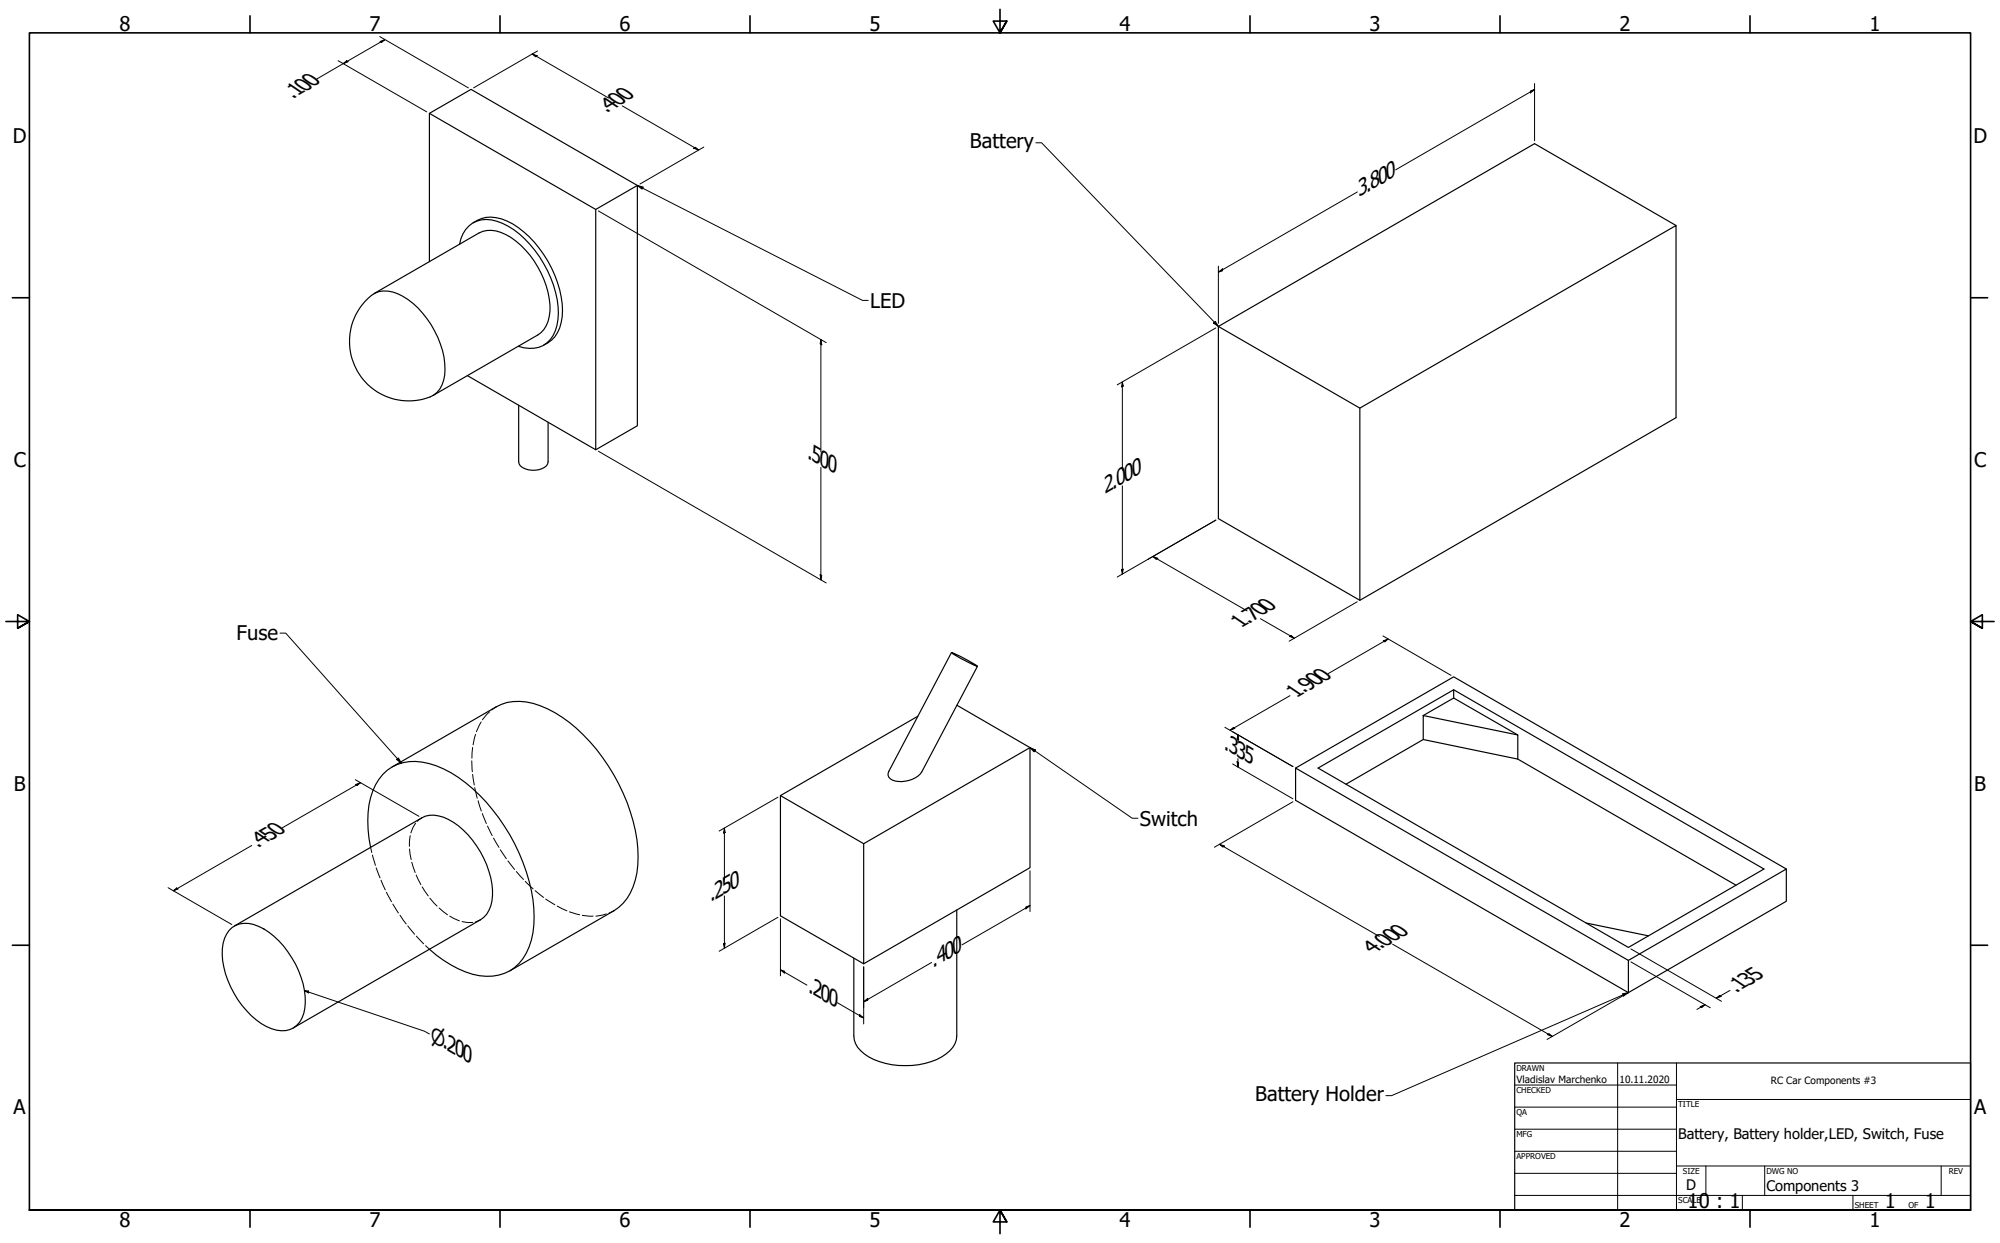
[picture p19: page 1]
Battery Holder

DRAWN Vladislav Marchenko | 10.11.2020 | RC Car Components #3

CHECKED

Battery, Battery holder,LED, Switch, Fuse

MFG

APPROVED

SIZE D | DWG NO Components 3 | REV

10 : 1 SCALE | | SHEET 1 OF 1

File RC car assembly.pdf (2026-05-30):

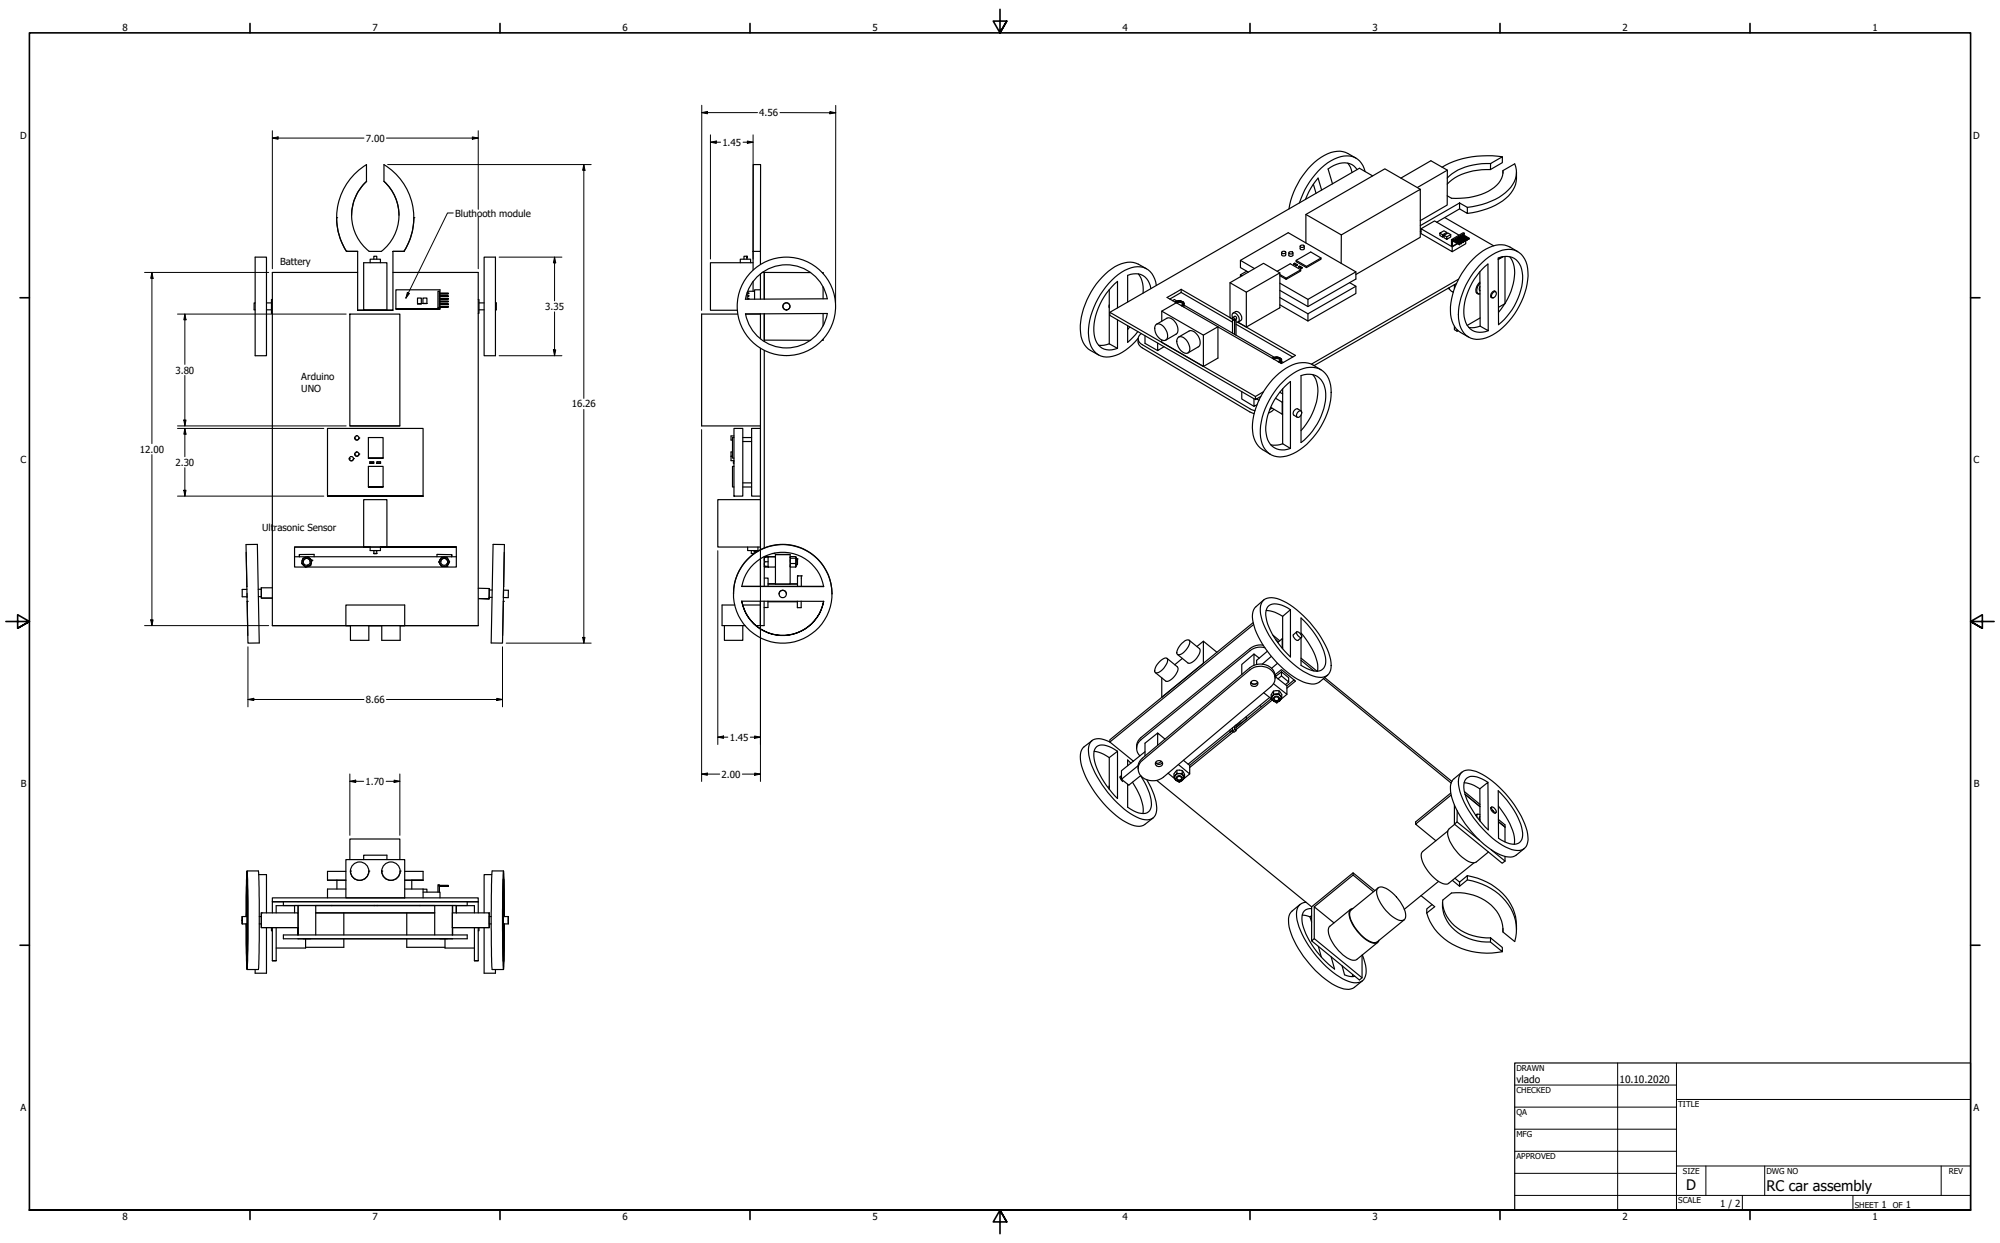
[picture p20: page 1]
Ultrasonic Sensor; Bluthooth module

DRAWN vlado | 10.10.2020

CHECKED

MFG

APPROVED

SIZE D | DWG NO RC car assembly | REV

SCALE 1 / 2 | | SHEET 1 OF 1

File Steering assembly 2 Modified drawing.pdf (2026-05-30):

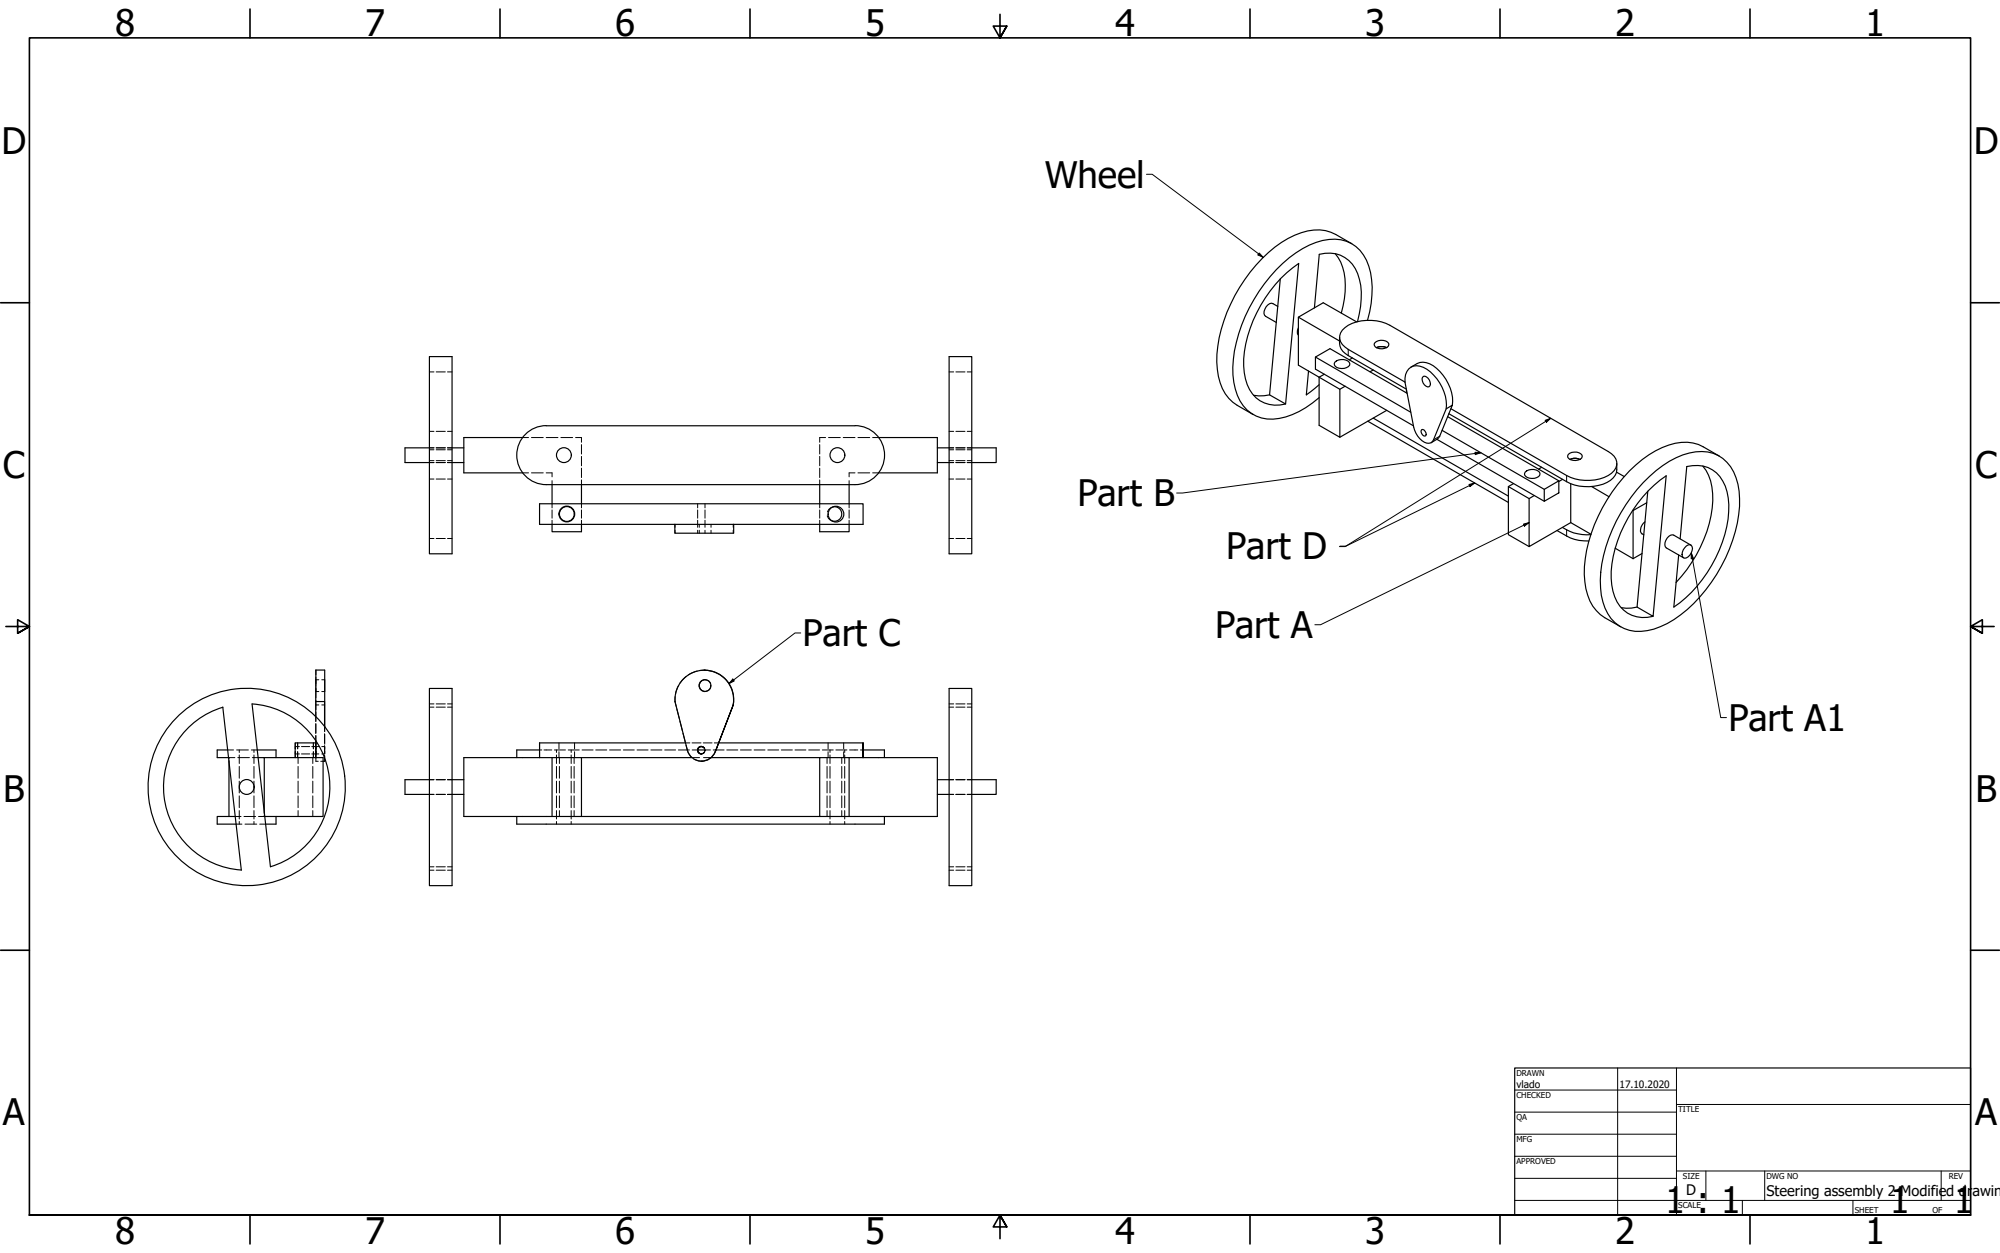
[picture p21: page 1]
SHEET; Steering assembly 2 Modified drawing; Part C; Part A; Part B; Part D; Part A1

DRAWN vlado | 17.10.2020

CHECKED

MFG

APPROVED

SIZE D | DWG NO | REV

SCALE

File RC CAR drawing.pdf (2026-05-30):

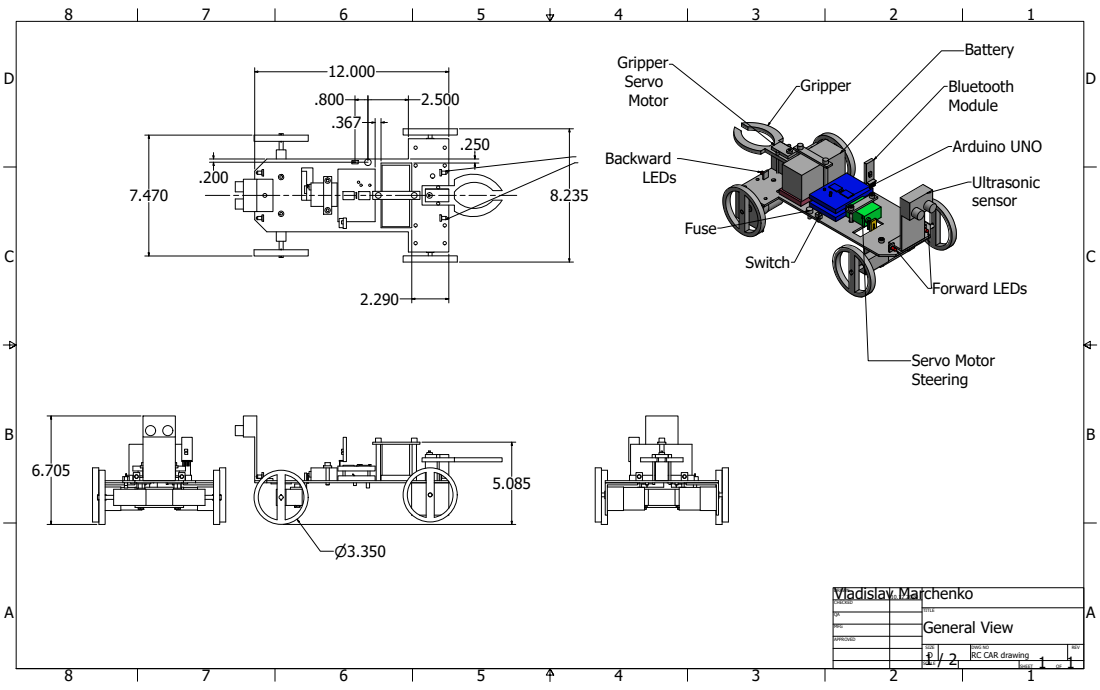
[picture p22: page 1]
General View; Arduino UNO; Forward LEDs; Servo Motor

Vladislav10.1M2.20a20rchenko DRAWN

CHECKED

MFG

APPROVED

SIZE D | DWG NO RC CAR drawing | REV

SCALE | | SHEET 1 OF 1

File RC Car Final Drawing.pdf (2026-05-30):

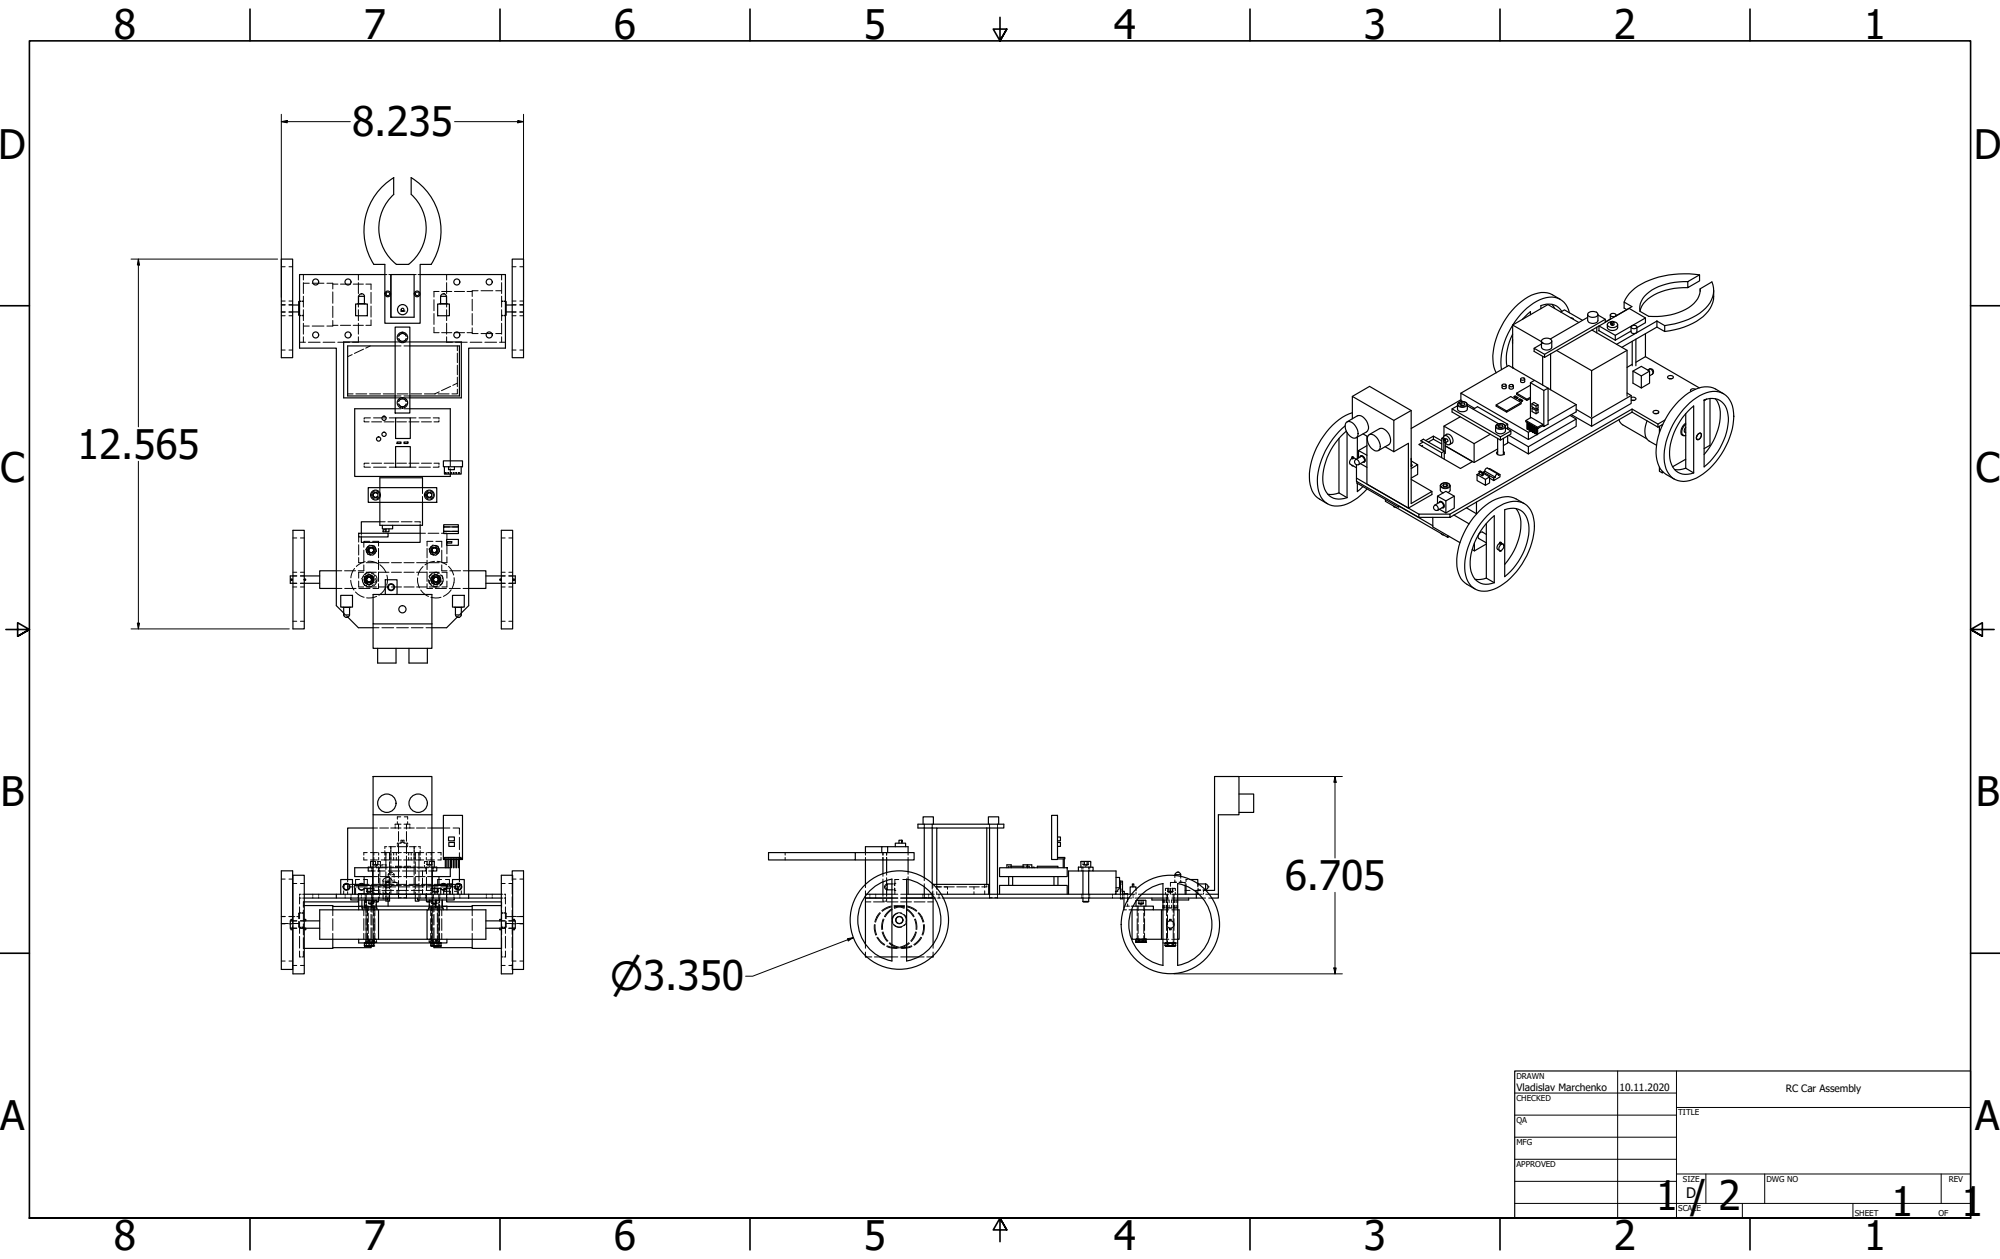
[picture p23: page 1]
SHEET

DRAWN Vladislav Marchenko | 10.11.2020 | RC Car Assembly

CHECKED

MFG

APPROVED

SIZE D | DWG NO | REV

SCALE

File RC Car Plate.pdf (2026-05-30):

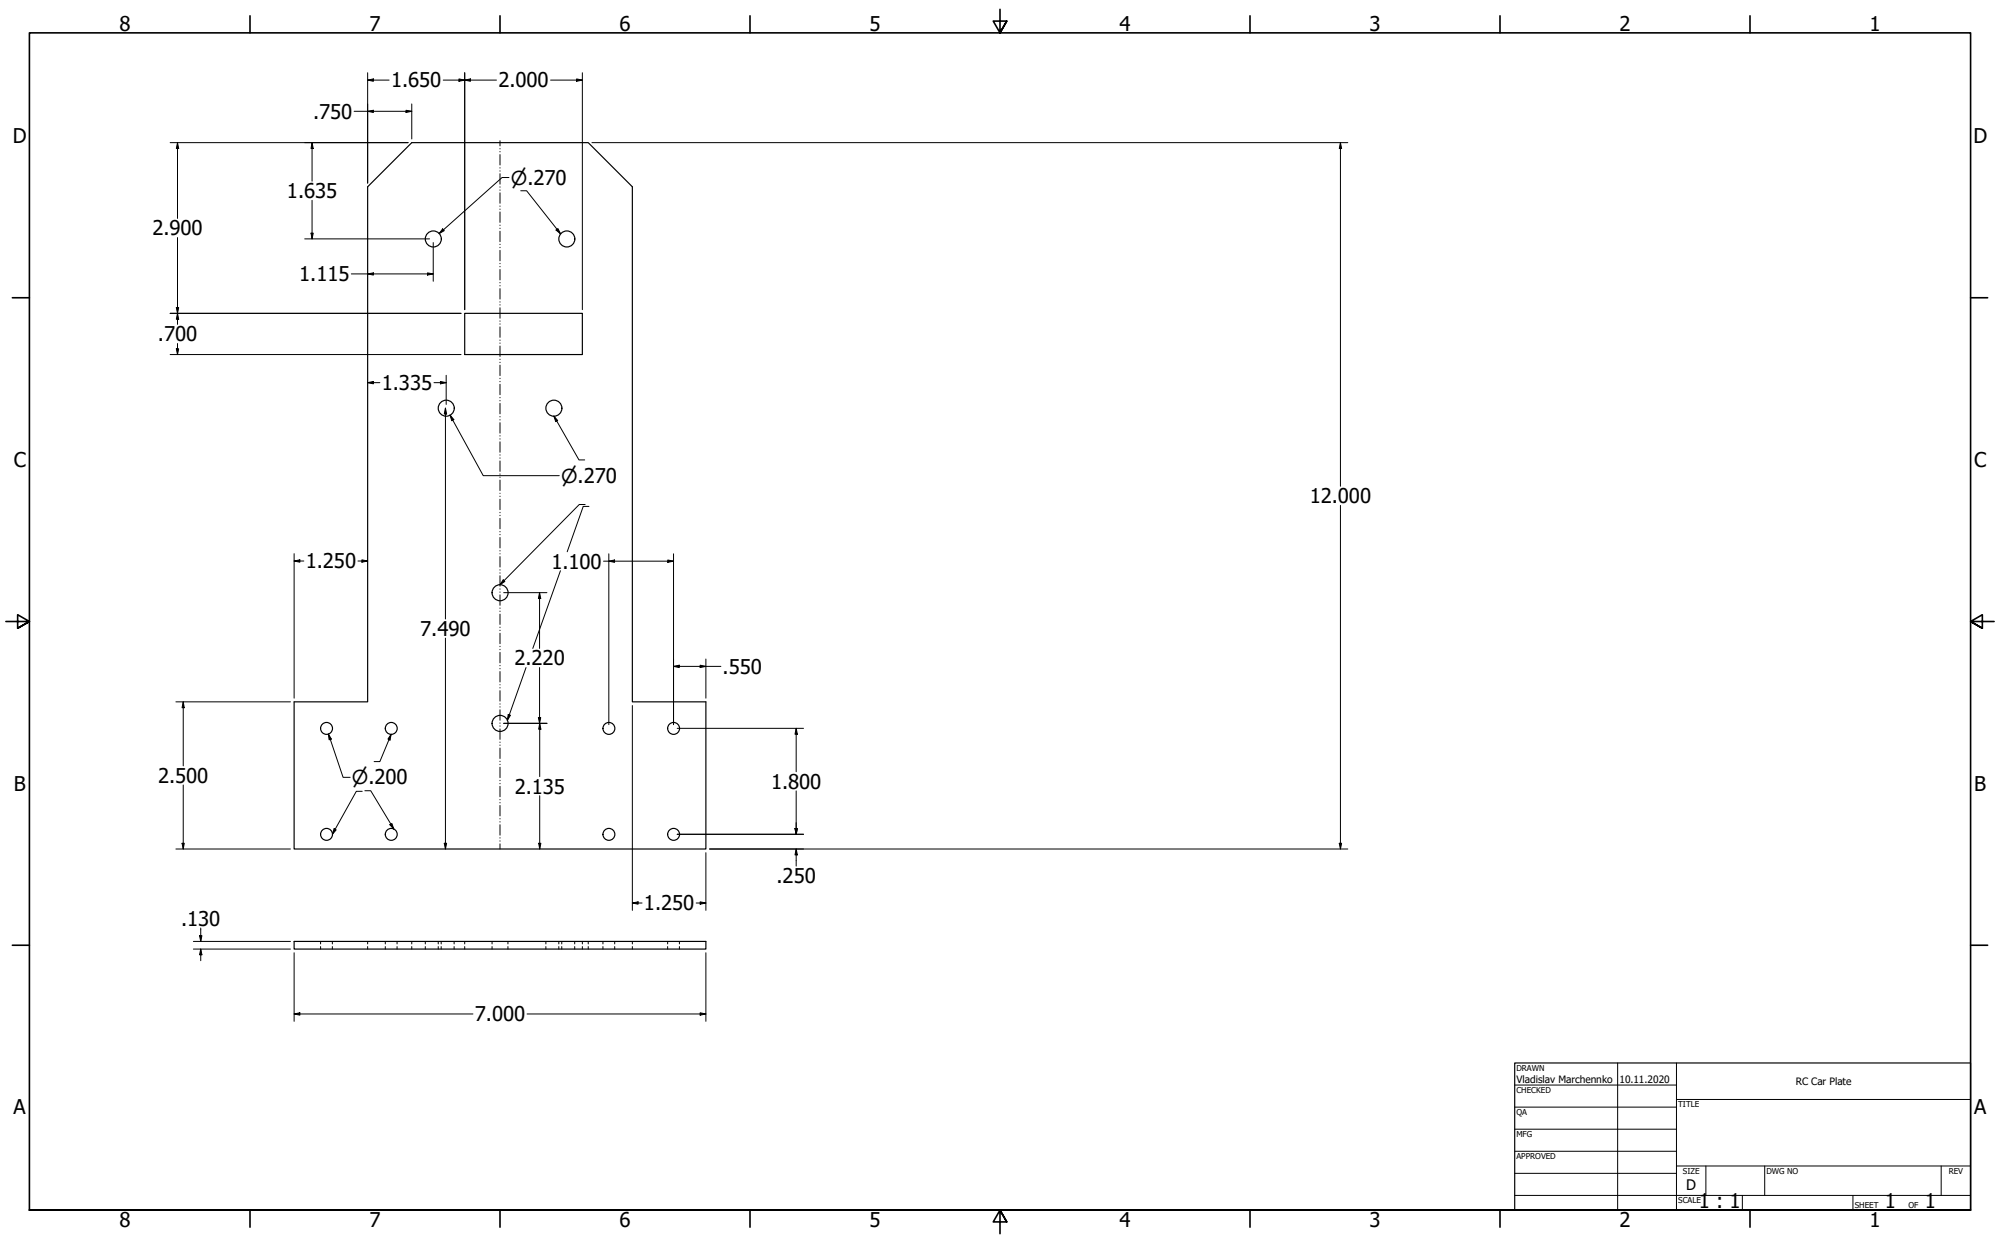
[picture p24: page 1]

DRAWN Vladislav Marchennko | 10.11.2020 | RC Car Plate

CHECKED

MFG

APPROVED

SIZE D | DWG NO | REV

1 : 1 SCALE | | SHEET 1 OF 1

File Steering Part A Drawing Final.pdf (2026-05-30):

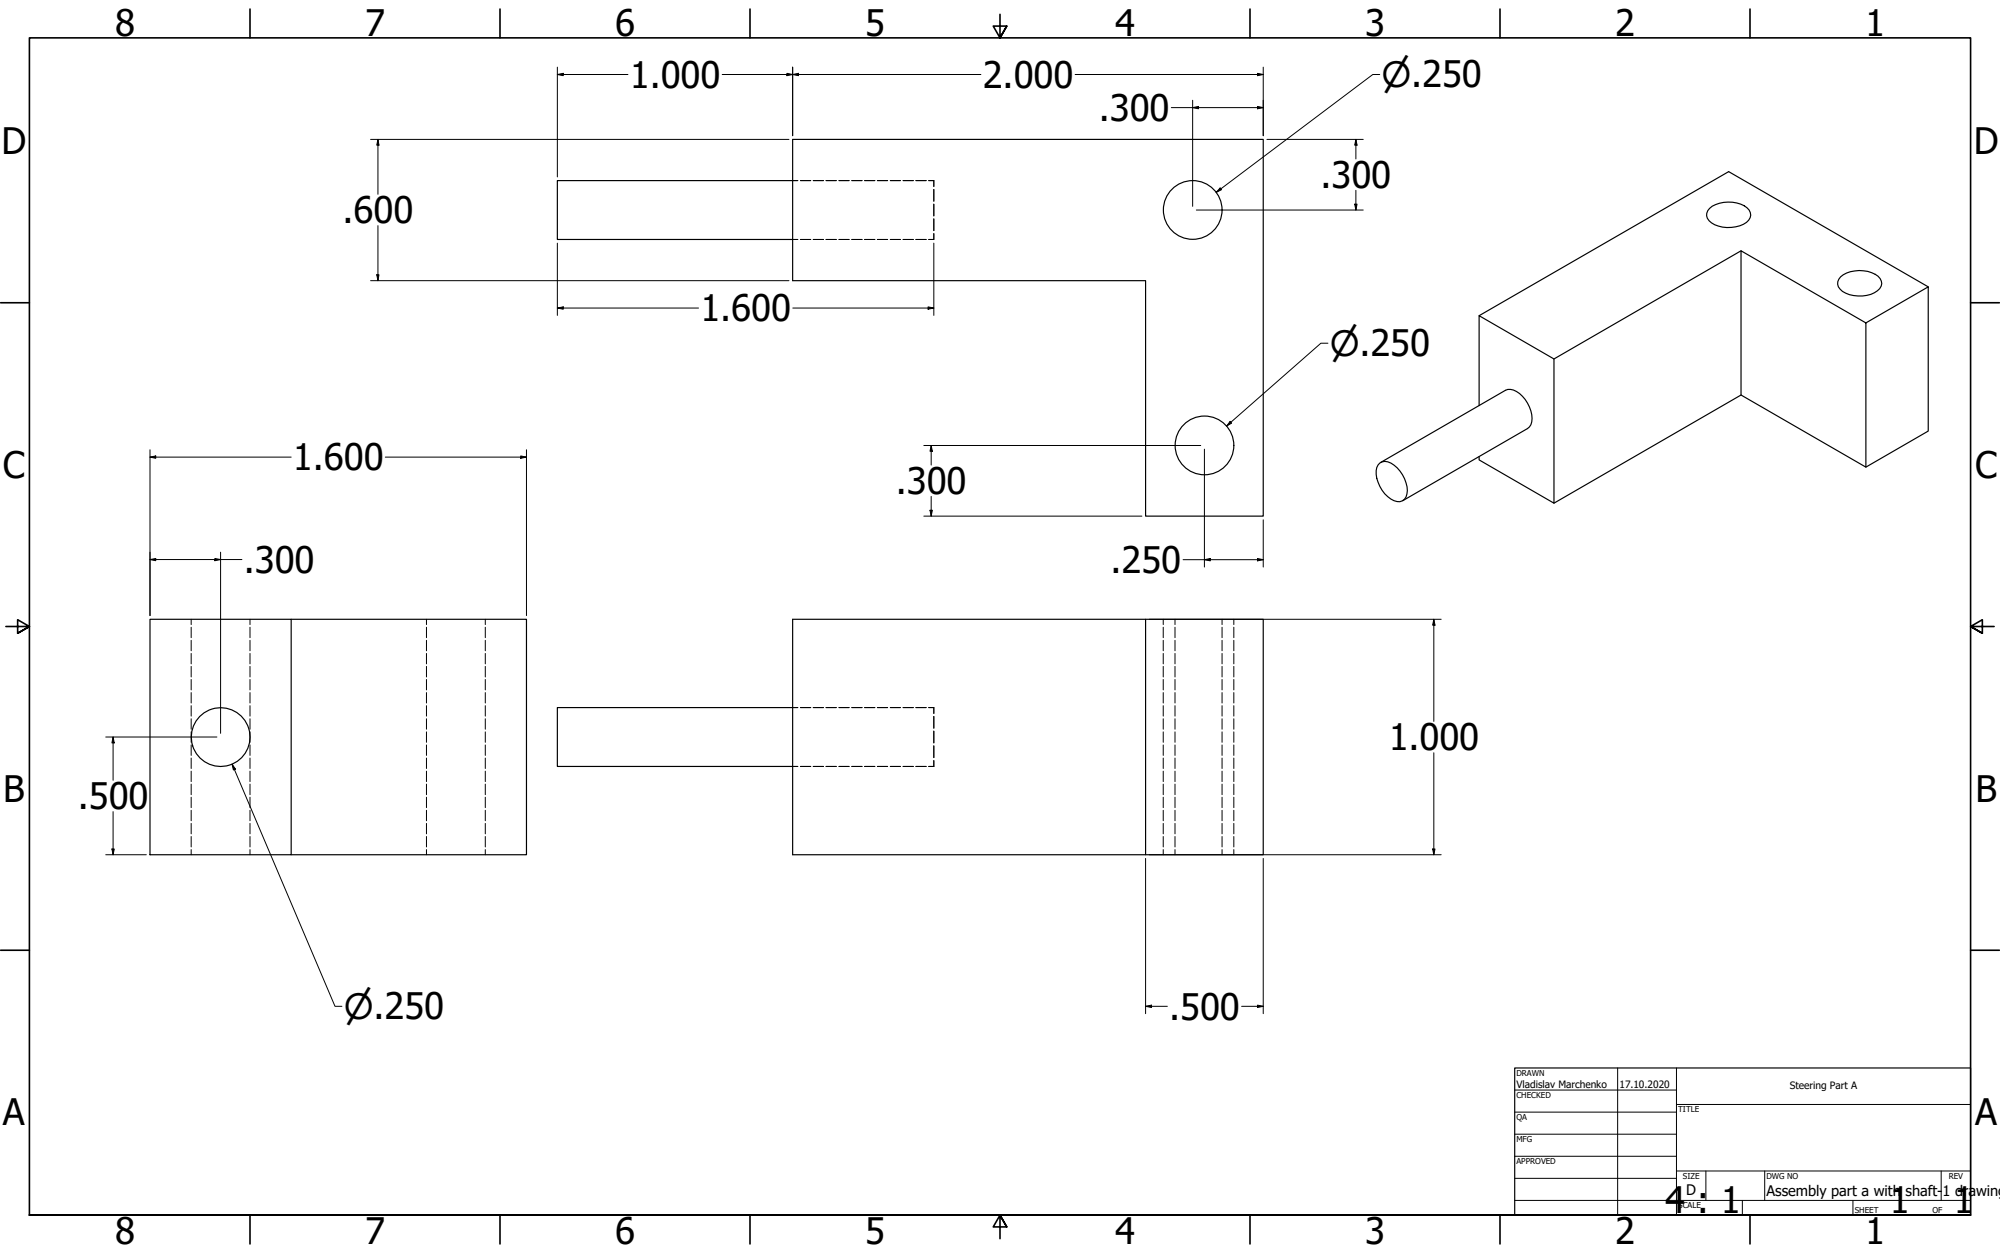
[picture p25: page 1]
SHEET

DRAWN Vladislav Marchenko | 17.10.2020 | Steering Part A

CHECKED

MFG

APPROVED

SIZE D | DWG NO | REV

Assembly part a with shaft-1 drawing

SCALE
